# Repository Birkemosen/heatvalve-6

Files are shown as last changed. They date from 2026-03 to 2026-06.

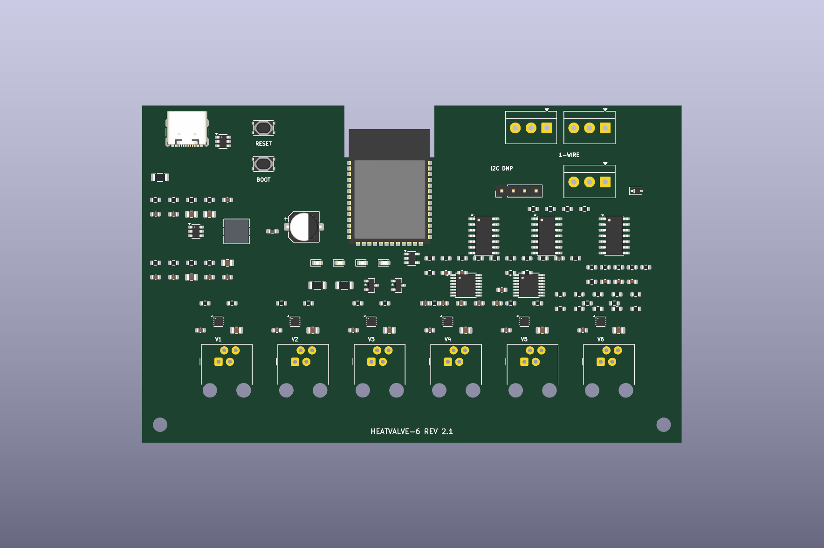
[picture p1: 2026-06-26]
hardware/heatvalve-6-rev2.1/board-preview.png

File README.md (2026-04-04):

# HeatValve-6

ESPHome firmware for the HeatValve-6 underfloor heating controller on ESP32-S3 with 6 DRV8215 I2C motor drivers.

This repository is now ESPHome-only. The legacy PlatformIO and ESP-IDF source tree has been removed.

## Repository Layout

```text
heatvalve-6/
├── heatvalve-6.yaml   # Main ESPHome firmware config
├── secrets.yaml       # Local secrets template (gitignored)
├── components/        # Custom ESPHome external components
│   ├── hv6_config_store/
│   ├── hv6_valve_controller/
│   └── hv6_zone_controller/
├── docs/
├── README.md
└── changelog.md
```

## What Is In The Firmware

- ESPHome on ESP-IDF
- 6-zone valve control with DRV8215 over I2C
- Custom C++ external components for config storage, valve control, and zone control
- Native ESPHome WiFi, API, OTA, web server, display, and climate entities
- DS18B20 1-Wire temperature sensors
- SSD1306 OLED support
- WS2812 status LED

## Hardware Mapping

| GPIO | Function |
|---|---|
| GPIO1 | Motor current sense ADC |
| GPIO2 | DRV8215 nSLEEP |
| GPIO7 | DRV8215 nFAULT |
| GPIO8 | I2C SDA |
| GPIO9 | I2C SCL |
| GPIO12 | 1-Wire bus |
| GPIO48 | WS2812 status LED |

### DRV8215 Addresses

| Zone | Address |
|---|---|
| 1 | 0x30 |
| 2 | 0x31 |
| 3 | 0x32 |
| 4 | 0x35 |
| 5 | 0x33 |
| 6 | 0x34 |

Only one motor should run at a time because current sensing is shared.

## Quick Start

1. Edit `secrets.yaml` with your WiFi, API, OTA, and optional MQTT values.
2. Replace the placeholder DS18B20 addresses in `heatvalve-6.yaml` after first discovery.
3. Build or deploy from the repo root.

Preferred workflow:

```bash
make build
make deploy
make logs
```

If you want USB flashing explicitly:

```bash
make deploy PORT=/dev/cu.usbmodemXXXX
```

If you want OTA to a specific host/IP:

```bash
make ota HOST=192.168.1.50
```

The `Makefile` automatically uses `.venv/bin/esphome` when present.

Direct ESPHome commands still work:

```bash
esphome run heatvalve-6.yaml
```

For config validation only:

```bash
esphome config heatvalve-6.yaml
```

## Notes

- The current firmware layout assumes the ESPHome config lives at the repository root.
- `secrets.yaml` is kept as a local template and remains gitignored.
- The repository has not been fully compile-tested yet after the migration.

## Documentation

- [docs/ARCHITECTURE.md](docs/ARCHITECTURE.md)
- [docs/ecodan_integration.md](docs/ecodan_integration.md)
- [docs/esp32-s3_ufh_pcb_solution.md](docs/esp32-s3_ufh_pcb_solution.md)
- [docs/schematics/rev3_wroom1/esp32_s3_wroom1_n16r8_controller.md](docs/schematics/rev3_wroom1/esp32_s3_wroom1_n16r8_controller.md)

## Inspiration & Credits

This project was inspired by and builds upon ideas from:

- [VdMot_Controller](https://github.com/Lenti84/VdMot_Controller) by Lenti84 — multiplexed motor control and current-based endstop detection for Homematic HmIP-VDMOT valve actuators
- [floor-heating-controller](https://github.com/nliaudat/floor-heating-controller) by nliaudat — BEMF analysis and trigger calculations for valve motor tachometry
- [Motor Controller Tachometer](https://yyao.ca/projects/motor_controller_tachometer/) by Yi Yao — back-EMF tachometer circuit design

## License

See [LICENSE](LICENSE) file.

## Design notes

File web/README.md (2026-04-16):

# HeatValve-6 ESP Dashboard

A lightweight, modular, framework-free dashboard optimized for ESPHome devices.

## Features
- Ultra-lightweight runtime
- Modular component system
- SSE real-time updates
- Offline mock mode
- SVG flow diagram with motor animation

## Structure
web/
  dashboard.js
  dashboard-src/
    core/
    utils/
    components/
    app/

## Usage
Include dashboard.js and mount to #app.

## Build
Use esbuild to bundle into a single file.

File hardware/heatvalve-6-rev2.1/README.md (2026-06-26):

# HeatValve-6 Rev 2.1 hardware

Editable KiCad 10 design for the USB-C-powered, six-channel DRV8837 HeatValve controller.

## Design state

- Schematic: complete first electrical-review revision; KiCad ERC reports 0 errors.
- PCB: compact four-layer 120 x 75 mm placement review with 128 electrical
  footprints, two M3 holes, an antenna notch, GND/+3V3 inner planes, and an
  intentionally unrouted ratsnest.
- Fabrication status: **not released**. Routing, mechanical confirmation, and final
  footprint/availability review are still required.
- PCB DRC: not current; KiCad CLI 10.0.3 aborts on both the original and updated
  board. See `drc.rpt` and rerun DRC in PCB Editor after routing.
- Prototype tuning: BEMF filter/gain/blanking, force threshold, engagement signature,
  and optional parallel shunt.

## Generate and validate

```bash
PYTHONPATH=/private/tmp/kicad_pydeps HOME=/private/tmp \
  python3 hardware/heatvalve-6-rev2.1/generate_kicad.py

kicad-cli sch erc \
  --output hardware/heatvalve-6-rev2.1/erc.rpt \
  hardware/heatvalve-6-rev2.1/heatvalve-6-rev2.1.kicad_sch

/Applications/KiCad/KiCad.app/Contents/Frameworks/Python.framework/Versions/3.9/bin/python3.9 \
  hardware/heatvalve-6-rev2.1/generate_pcb.py

kicad-cli pcb drc \
  --output hardware/heatvalve-6-rev2.1/drc.rpt \
  hardware/heatvalve-6-rev2.1/heatvalve-6-rev2.1.kicad_pcb
```

The committed `.kicad_sch` is usable without the Python generator dependency.

## Important design decisions

- Motors and logic operate from the MT2492-generated 3.3 V rail.
- Only one motor may run at a time.
- All DRV8837 ground returns meet at `SHUNT`; `RSH1` is the only normal return to system ground.
- `RSH1` is 1.0 ohm and INA180A1 provides x20 gain: 30 mA = 0.60 V,
  60 mA = 1.20 V, and 150 mA = 3.00 V. This preserves the pin-engagement peak.
- `R14`, `C13`, and `D5` provide additional ADC filtering and rail clamp protection.
- The hardware force-limit comparator reads the raw Kelvin shunt and remains effective if the ADC path saturates.
- Two 74HC4051 selectors connect only the active motor's A/B terminals to a
  shared differential BEMF front end. `ADC_BEMF` retains the raw waveform and
  `TACHO_EDGE` feeds PCNT after AC gain and hysteresis.
- Shunt ripple is not used as authoritative motion evidence. Firmware must qualify
  tacho edges against BEMF waveform, direction, switching blanking, and cadence.
- The latch powers up with `DRIVE_PERMIT` low and must be explicitly armed by firmware.
- Three OneWire connectors share GPIO42. The DNP I2C header uses GPIO1/GPIO2.
- Motor jacks use the center pair: pin 2 `MOT_A`, pin 3 `MOT_B`.

See `design-review.md` for calculations and release gates, and
`measurement-and-position.md` for engagement, modulation, endstop, and position logic.

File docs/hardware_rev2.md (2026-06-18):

# HeatValve-6 — Rev 2 board design (shared-shunt, dumb-driver)

Status: **design draft for a PCB respin.** Component values marked _(validate)_ are
reasoned starting points to confirm on a prototype channel, not final.

## 1. Goals

- **Safe, deterministic calibration** without the DRV8215's fragilities.
- **Fewest components / simplest layout** that is still **resilient** (per-zone failure
  granularity, no single-driver SPOF).
- Software-based hydraulic balancing (room-temp feedback, **no return probes** — see
  [adaptive_balancing.md](adaptive_balancing.md)), so per-loop return sensing is dropped.
- All parts orderable at LCSC/JLCPCB.

## 2. Architecture in one paragraph

Only one valve moves at a time, so **all sensing collapses onto a single shared low-side
shunt** (the VdMot insight). Six **dumb single H-bridges** (no I²C, no per-driver current
sense) are driven directly from GPIO and share one ground-return shunt. That one shunt
yields three things by splitting the signal: **DC current** (endstop/stall), **AC tacho**
(commutation ripple → edges → position), and a **hardware force-limit** (window comparator
with a firmware-set threshold → latch → global `nSLEEP` cutoff). This removes the six-way
IPROPI wire-OR, the I²C addressing, and the per-driver `RIPROPI` networks of the old board,
while *adding* a tacho and a force-limit it never had.

```mermaid
flowchart LR
  MCU[ESP32-S3-WROOM-1-N16R8]
  subgraph DRV[6x dumb single H-bridge DRV8837]
    D1[ch1] & D2[ch2] & D3[ch3] & D4[ch4] & D5[ch5] & D6[ch6]
  end
  SHUNT[shared low-side shunt Rs]
  FE[analog front-end]
  LATCH[force-limit latch]

  MCU -- PH/EN x6 --> DRV
  DRV -- all GND --> SHUNT --> FE
  FE -- DC current --> MCU
  FE -- AC tacho edges --> MCU
  MCU -- PWM-DAC threshold --> FE
  FE -- over-current --> LATCH
  MCU -- reset --> LATCH
  LATCH -- state --> MCU
  LATCH -- nSLEEP low = cut all --> DRV
  MCU -- BLE room temps --> MCU
  MCU -- 1-Wire manifold supply/return --> MCU
```

(A standalone, renderable version of this is in
[hardware_rev2_block.dot](hardware_rev2_block.dot) — `dot -Tsvg hardware_rev2_block.dot`.)

## 3. Power

| Rail | Source | Notes |
|---|---|---|
| `VM` (motor) | external supply (e.g. 12 V) | TVS (SMAJ-series) + bulk electrolytic + 100 nF per driver |
| `+3V3` | AP2112K-3.3 LDO (or small buck) | **≥ 500 mA** for WiFi TX peaks; bulk + local decoupling |
| `VBIAS` (≈½·3V3) | coarse divider from `+3V3` | AC-tacho bias only (centres the comparator); **not** a precision current ref |

## 4. Motor drivers — 6× dumb single H-bridge

- **DRV8837** (single H-bridge, `IN1`/`IN2` or `PH`/`EN`, `nSLEEP`, ~1.8 A, no sense, no
  I²C). Six identical blocks → copy-paste layout, **1-zone failure granularity**.
- Per driver: 2 control GPIO + `nSLEEP` + 100 nF decoupling + (optional) small output cap.
  **No `RIPROPI`, no current-set resistor, no I²C pull-ups.**
- **All six `nSLEEP` tie to one net = the force-limit "drive permit."** When the latch
  trips, `nSLEEP` → low → **all bridges Hi-Z instantly**, no per-driver AND gates needed.
- **Drive fixed duty** (`EN` high, no PWM/brake) during a move so the active motor's current
  flows continuously through the shunt → clean tacho + continuous current. Soft-approach near
  an endstop uses position (tacho), not duty chopping, to keep the ripple clean.

```
        VM
        │
   ┌────┴────┐  DRV8837 (one of six)
   │  H-brdg │  IN1 ◄─ GPIO_PHn
   │         │  IN2 ◄─ GPIO_ENn   (fixed-duty during move)
   │         │  nSLEEP ◄─ DRIVE_PERMIT (shared, from latch)
   └──┬───┬──┘
   OUT1   OUT2 ──► motor n
        │
       (chip GND)
        └──────────────► shared shunt node  (all six chip grounds join here)
```

## 5. Shared sense front-end (the heart of the board)

One shunt `Rs` in the **common return of all six driver grounds**. Because only one motor is
energized, `Rs` carries that motor's current (+ a small, calibratable quiescent offset from
the idle chips' awake current). **The current is unipolar**: a full H-bridge always sources
from `VM` and returns through GND no matter which way the motor spins, so the chip-GND shunt
only ever sees positive magnitude — *direction is known from the commanded `PH`*, not the
sign. (This is the key difference from VdMot, whose shunt sat in the motor common and so
swung bipolar and needed a `VREF/2` mid-rail.) That makes the front-end single-ended and the
force-limit a single comparator, not a window.

```
 driver GNDs ─┬─ Rs ─┬─ system GND      V_sense = I·Rs  (>= 0, unipolar)
              │      │
              │      ├─► [non-inv gain] ───────────────► ADC_CURRENT          (A) DC current
              │      │
              │      ├─► [HPF, bias=VBIAS] ─► [gain] ─► [comp + hyst] ─► PCNT  (B) tacho edges
              │      │
              │      └─► [comparator, thr = PWM-DAC] ──► LATCH                 (C) force-limit
```

`VBIAS` (≈ ½·3V3) is a **coarse divider**, used only to centre the AC-coupled tacho so the
comparator sees both edges — it is *not* a precision current reference (there isn't one).

### (A) DC current — endstop / stall / pin-engagement

- `Rs` ≈ **2.2 Ω _(validate)_** — at 50 mA → 110 mV; at a 100 mA stall ceiling → 220 mV;
  power < 25 mW. Drop is negligible vs `VM`.
- **Single-ended non-inverting amp** on `V_sense` (unipolar, sits at 0 V up), gain ≈
  **×8–10 _(validate)_** → ~1 V full-scale into the ADC. No precision reference needed.
- A constant **idle-chip offset** (all six share `nSLEEP`, so all are awake ~1–2 mA each)
  rides on `V_sense`; it's DC, so the firmware's per-pass `cal_baseline` subtracts it (same
  mechanism as today). If the offset is too large, lower `Rs` or gate `nSLEEP` per channel.
- Firmware uses it as today: endstop threshold `mean_dir × factor`, hard cap, undercurrent
  disconnect, pin-engagement step — direction comes from the commanded `PH`, not the sign.

### (B) AC tacho — commutation ripple → position

- AC-couple `V_sense` (high-pass corner ≈ **30 Hz _(validate)_**, below commutation rate but
  above the slow current ramp), gain ≈ **×50–100 _(validate)_** to lift the small ripple.
- Into a comparator with **~10–20 mV hysteresis _(validate)_** → clean digital edges → MCU
  **PCNT** peripheral (hardware edge count). Re-zeroed at each endstop to kill drift.
- This is VdMot's "back-EMF" revolution count, taken from the shared current node.

### (C) Force-limit — configurable, hardware-fast

- **Single comparator** (current is unipolar): `V_sense`-amp vs threshold, set by a
  **PWM-DAC**: one MCU `LEDC` PWM → RC low-pass → comparator reference. (ESP32-S3 has **no
  DAC**, so PWM-DAC; an MCP4725/digipot is the cleaner one-chip alternative.)
- **Per-motor ceiling**: reprogram the PWM-DAC to `mean_i × factor` from telemetry before
  starting motor *i* — one comparator gives a per-motor configurable stall limit.
- Comparator → **latch** (D-FF / SR) → drives `DRIVE_PERMIT` (= all `nSLEEP`). Trip cuts the
  active motor in **µs**, in hardware, independent of the 10 ms firmware tick.
- **Latch controls to MCU**: `RESET` (GPIO out — firmware decides re-arm policy: on back-off,
  after a dwell, or next command) and `STATE` (GPIO in — logged as a fault, feeds relearn).

## 6. Optional BEMF stop-sense (DNP, populate-if-needed)

For the spring-assisted **open** endstop, a magnitude-independent "stopped?" signal is the
ideal backstop. Tap the six motor `OUT1/OUT2` pairs through a `CD74HC4051` (8:1) → divider →
ADC, sampled in a brief coast window. **Lay out, leave unpopulated.** Validate current-ripple
+ current-stall first; populate only if the open stroke proves marginal (see §11).

## 7. MCU & pin budget (ESP32-S3-WROOM-1-N16R8)

Reserve/avoid: flash/PSRAM pins (octal PSRAM on **R8** uses GPIO35–37; flash GPIO26–32),
strapping (GPIO0, 3, 45, 46), USB (19/20 if used).

| Function | Count | Notes |
|---|---|---|
| Driver `PH` (direction) | 6 | GPIO out |
| Driver `EN` (fixed-duty/PWM) | 6 | GPIO/`LEDC` out |
| Tacho edges | 1 | → `PCNT` |
| Current sense | 1 | ADC1 (unipolar; baseline subtracted in firmware) |
| Force-limit threshold | 1 | `LEDC` PWM-DAC |
| Latch reset / state | 2 | GPIO out + in |
| 1-Wire (manifold supply+return) | 1 | DS18B20 ×2 on one bus |
| BLE / WiFi | 0 | on-module |
| **Optional** BEMF mux select + ADC | 3+1 | DNP |
| **Total (core)** | **~20** | comfortable on WROOM-1 |

> `nSLEEP` is **not** an MCU pin — it's the latch's `DRIVE_PERMIT` net. `EN` can be plain
> GPIO (fixed-duty) since force-limit is hardware; use `LEDC` only if you want PWM soft-start.

## 8. Sensors

- **Room temperature** = the balancing feedback: BLE (Shelly BLU H&T) per zone, as today.
- **Manifold supply + return** DS18B20 pair on one 1-Wire bus — diagnostics only.
- **Per-loop return probes: removed.** Not an input to the room-temp balancer.

## 9. BOM (verified against LCSC / JLCPCB, June 2026)

JLC status: **Basic** = preloaded, no per-part feeder fee; **Extended** = orderable, small
setup fee. Stock/status changes — reconfirm at order time on `jlcpcb.com/parts`. For jellybean
analog (LM324/LM339) pick whichever manufacturer variant JLC currently flags Basic/Preferred.

| Ref | Part | LCSC / JLC | JLC status | Qty | Notes |
|-----|---|---|---|-----|---|
| U1 | ESP32-S3-WROOM-1-N16R8 | **C2913202** | Extended (stocked) | 1 | 16 MB flash / 8 MB PSRAM; `-1U` = C3013946 |
| U2–U7 | DRV8837**DSGR** | **C39159** | Extended | 6 | dumb H-bridge, `IN1/IN2`, `nSLEEP`, `VM`+`VCC`; WSON-8. **Netlist targets this (non-C) pinout** — the `C` variant (C191000) drops `VCC` and re-maps pins, so don't swap without re-wiring |
| U8 | LM324 (quad op-amp) | **C351427** | Basic-class | 1 | current diff-amp + tacho gain + ref buffer (3 of 4) |
| U9 | LM339 (quad comparator) | **C504552** | Basic-class | 1 | tacho edge + force-limit window (3 of 4) |
| U10 | 74HC74D (dual D-FF) | **C27597** | Extended | 1 | force-limit latch (1 of 2) |
| U11 | AP2112K-3.3TRG1 | **C51118** | **Basic** | 1 | 3V3 LDO, 600 mA, SOT-25 |
| U12 | CD74HC4051PWR | **C352826** | Extended | 1 | **DNP** — optional BEMF mux (§6) |
| Rs | 2.2 Ω 0.25 W _(validate)_ | generic | Basic | 1 | shared shunt (1206 for power/heat) |
| D1 | SMAJ-series TVS (per `VM`) | generic | Basic | 1 | e.g. SMAJ15A for 12 V `VM` |
| C_bulk | 100–470 µF electrolytic | generic | Basic | 1–2 | `VM` bulk (motor inrush) |
| — | 100 nF ×~12, RC/divider/HPF passives | generic | Basic | — | decoupling, PWM-DAC RC, ref divider, AC-couple |

**Active-IC count: 10** (1 module + 6 drivers + 2 analog + 1 latch), of which only the module,
drivers, 74HC74 and (DNP) mux are Extended; everything else is JLC Basic. The two jellybean
analog ICs (LM324 + LM339) replace what would otherwise be six per-driver `RIPROPI`/sense
networks — they're the VdMot-precedented choice (VdMot used the LM224 = same LM324 family).

vs the old board: **− 6× `RIPROPI` networks, − I²C pull-ups/addressing, − per-driver config
passives; + 1 shunt, + LM324 + LM339, + 1 latch.** Net fewer parts, plus tacho + force-limit.

> Driver note: `DRV8837CDSGR` (C191000) is the cheapest well-stocked variant but is Extended.
> If you want to minimise Extended parts, `DRV8837DSGR` (**C39159**) is the other TI option;
> both are Extended (small H-bridges generally are). The LM324/LM339/AP2112K being Basic keeps
> the feeder-fee count low.

## 10. Net / connection list (capture this in EasyEDA/KiCad)

Power/ground nets omitted for brevity except where signal-relevant.

```
NET VM            : VMext, U2..U7.VM(1), C_bulk+, D1.cath              ; Rs is NOT here (low-side)
NET GND           : U1.GND, U11.GND(2), Rs.2, C_bulk-, U8.GND(11), U9.GND(12), U10.GND(7)
NET SHUNT         : Rs.1, U2..U7.GND(4), U8 current-amp in, U8 tacho AC-couple in, U9 force-limit in
NET VBIAS         : 3V3 divider mid, U8 tacho-amp bias, U9 tacho-comp ref     ; coarse, AC only
NET DRIVE_PERMIT  : U10.1Q(5), U2..U7.nSLEEP(7)                        ; latch trip -> all asleep
NET I_SENSE       : U8 current-amp out -> U1 ADC1 (GPIO4)
NET TACHO_EDGE    : U9 tacho-comp out -> U1 PCNT (GPIO15)              ; LM339 open-collector + pull-up
NET FLIM_THR      : U1 LEDC (GPIO16) -> RC -> U9 force-limit comp ref
NET FLIM_TRIP     : U9 force-limit comp out -> U10.1CLK(3)             ; open-collector + pull-up
NET LATCH_RESET   : U1 (GPIO17) -> U10.1nPRE(4)                        ; pulse low = re-arm (Q->1)
NET LATCH_STATE   : U10.1nQ(6) -> U1 (GPIO18)                          ; high = tripped (logged)
NET PH1..PH6      : U1 GPIO9..14 -> U2..U7.IN1(6)
NET EN1..EN6      : U1 GPIO47,48,38,39,40,41 -> U2..U7.IN2(5)
NET MOT1..MOT6    : U2..U7.OUT1(2)/OUT2(3) -> manifold actuator n
NET OW_MANIFOLD   : U1 (GPIO42) -> DS18B20 supply + return
; --- optional / DNP ---
NET BEMF_x        : U2..U7 OUT pairs -> U12 mux -> U1 ADC1 (GPIO6); mux sel -> U1 GPIO1,2,21
```
The machine-importable KiCad netlist of this is
[hardware_rev2.net](hardware_rev2.net) (`File > Import > Netlist` in EasyEDA / KiCad).
Op-amp/comparator support passives (gain resistors, hysteresis, pull-ups, PWM-DAC RC) are
included with _(validate)_ values — confirm on the prototype channel (§12).

## 11. Firmware mapping

- **PCNT** counts `TACHO_EDGE`; position = count from the last endstop re-zero. Flow band
  (pin-engagement → close) is the loaded, strong-ripple region — count there; coarse-time the
  open dead band.
- **ADC** reads `I_SENSE − VREF_HALF` (signed current) for endstop / stall / pin step.
- **LEDC PWM-DAC** sets `FLIM_THR = mean_i × factor` per motor before each move.
- **GPIO** drives `PH/EN` fixed-duty; reads `LATCH_STATE` (force-limit fired → fault/relearn),
  pulses `LATCH_RESET` per the chosen re-arm policy.
- Calibration logic (close→open→close, pin-engagement re-baseline, runtime cap) carries over;
  the tacho turns time-estimates into real position and makes already-at-stop detectable.

## 12. Bring-up / validation (prototype one channel first)

1. **Shunt + DC current**: drive a motor, confirm signed current matches a meter across the
   13–50 mA range; null the idle-chip quiescent offset via `VREF/2`.
2. **Tacho integrity** _(gate to populating all six)_: drive fixed-duty, verify the AC chain
   produces clean edges; count a full **flow-band** stroke, re-zero at close, check
   **repeatability within a few %**. Tune HPF corner / gain / hysteresis.
3. **Force-limit**: set `FLIM_THR` low, stall the motor, confirm `nSLEEP` cutoff in µs and the
   latch state/reset path; then set the real per-motor ceiling.
4. **Open endstop**: if the open stroke can't be caught reliably by current + tacho, **populate
   the BEMF path** and validate stop-by-BEMF.
5. Only then lay out and stuff all six identical blocks.

## 13. Resilience

- 6 independent bridges → **one driver dies = one zone**, rest keep running (same as today).
- Shared points: the shunt/front-end and the latch. Both are tiny, low-stress silicon; a
  front-end failure degrades to **open-loop time-driven** moves (limp mode), not loss of heat.
- NO valves fail **open** (warm) on power/driver loss — the safe direction for heating.
- Want lower part count over granularity? Swap 6 singles → **3 dual H-bridges** (DRV8833),
  2-zone granularity, same shunt/front-end.

## 14. Open items to finalize on the prototype

- `Rs` value + diff-amp gain for your exact `VM` and motor current band.
- Commutation-ripple frequency (sets the HPF corner and comparator hysteresis) — **measure**.
- Per-motor `factor` for the force-limit ceiling vs learned mean.
- Whether the BEMF path is needed (open-endstop margin).

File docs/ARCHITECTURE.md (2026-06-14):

# HeatValve-6 Architecture

## System Overview

HeatValve-6 is a 6-zone underfloor heating (UFH) valve controller built on ESP32-S3 with
ESPHome firmware. Custom C++ components run as FreeRTOS tasks alongside the ESPHome main
loop and separate hardware control (motor FSM, endstop detection) from heating logic
(zone state machine, control algorithms, hydraulic balance).

```
┌──────────────────────────────────────────────────────────────┐
│                     Config Composition                       │
│  configurations/heatvalve-6-ble.yaml → heatvalve-6.yaml      │
│  (substitutions + packages: board / hardware / network /     │
│   zones)                                                     │
└────────────────────────────┬─────────────────────────────────┘
                             ▼
┌──────────────────────────────────────────────────────────────┐
│                    Custom C++ Components                     │
│                                                              │
│  hv6_config_store ← hv6_valve_controller ← hv6_zone_controller
│                                                  ↑           │
│                                          hv6_asgard_bridge   │
│                                          hv6_forecast        │
│                                          hv6_dashboard       │
└────────────────────────────┬─────────────────────────────────┘
                             ▼
┌──────────────────────────────────────────────────────────────┐
│                       Hardware Layer                         │
│  • 6× DRV8215 I2C H-bridge motor drivers                     │
│  • Shared IPROPI current-sense ADC (GPIO7)                   │
│  • 1-Wire DS18B20 probes (8 slots)                           │
│  • BLE (BTHome / Shelly BLU H&T)                             │
│  • Status LED, display                                       │
└──────────────────────────────────────────────────────────────┘
```

## Repository Structure

```
heatvalve-6/
├── heatvalve-6.yaml          Shared base config (substitutions + packages)
├── configurations/
│   └── heatvalve-6-ble.yaml  Active build entrypoint (adds BLE package)
├── packages/
│   ├── board/                ESP32-S3 board definition
│   ├── hardware/             BLE, display, I2C, motors, LED, 1-Wire, sensors
│   ├── network/              WiFi, API, OTA, Asgard bridge, forecast
│   └── zones/                Climate entities, zone sensors, UI, dashboard wiring
├── components/               Custom ESPHome external components (C++)
│   ├── hv6_config_store/     NVS persistence (DeviceConfig struct)
│   ├── hv6_valve_controller/ Motor FSM, endstop detection, ripple counting
│   ├── hv6_zone_controller/  Zone state machine, algorithms, hydraulic balance
│   ├── hv6_asgard_bridge/    Weighted house temp → Asgard/Ecodan thermostat
│   ├── hv6_forecast/         Open-Meteo wind-aware per-zone preload
│   └── hv6_dashboard/        HTTP API (/api/hv6/v1), dashboard asset serving
├── web/
│   ├── dashboard-src/        Dashboard source (modular JS, esbuild)
│   └── dashboard.js          Bundled artifact (committed, embedded in firmware)
├── test/ripple_counter/      Host-side unit tests (clang++, no ESP-IDF)
├── docs/                     Architecture, API contract, integration docs
└── Makefile                  Build/deploy/test targets
```

## FreeRTOS Task Layout

| Task | Core | Priority | Period |
|---|---|---|---|
| `hv6_valve` (motor FSM) | 1 | 7 | 10 ms tick |
| `hv6_ripple` (DMA ADC) | 1 | 7 | continuous |
| `hv6_zone` (control cycle) | 0 | 6 | 10 s (configurable) |
| `hv6_asgard` (HTTP) | 1 | 1 | 30 s push (coordinator only) |
| `hv6_forecast` (HTTPS) | 1 | 1 | 1 h fetch / 5 min recompute |
| `hv6_nvs` (flash commit) | 1 | 1 | event-driven |
| ESPHome loopTask | 1 | 1 | — |

Cross-task state is exchanged via FreeRTOS queues and mutexes. Dashboard snapshots are
assembled in `hv6_dashboard::loop()` (main loop) under a dedicated `snapshot_mutex_`.

## Data Flow

### Local Control

```
Temp source (DS18B20 / BLE) → Zone state machine → Control algorithm → Hydraulic balance
                                   ↑                (tanh/linear/PID)        ↓
                              Setpoint + offsets                       Valve position
                                                                            ↓
                                                                   Motor FSM (one at a time)
                                                                            ↓
                                                                       DRV8215 I2C
```

### Setpoint-offset command path

On-device optimizers (currently `hv6_forecast`) write per-zone setpoint-offset / preheat
commands through `Hv6ZoneController::apply_helios_command()`. Offsets are clamped in
firmware by per-zone safety limits; if a producer goes stale, its offsets are cleared and
local control continues unchanged. `HeliosConfig.enabled` (NVS) acts as a quiesce gate so
a producer can stand down if an external optimizer is ever reintroduced.

Whole-house MPC is provided by Odin via the [Asgard / Ecodan bridge](ecodan_integration.md),
not an external HTTP optimizer — the previous `hv6_helios_client` was removed. Removing any
producer reverts transparently to local control: no vendor lock-in, no firmware dependency
on an external service.

## Hardware Layer

- **Motor Control**: 6× DRV8215 I2C H-bridges with shared IPROPI ADC current sensing
- **Constraint**: One motor at a time (all IPROPI outputs wire-ORed to GPIO7; the valve
  FSM enforces sequential execution)
- **Endstop Detection**: Four-path software detection (threshold, slope, hard cap, ripple
  limit) with per-direction parameters — see [endstop_detection.md](endstop_detection.md)
- **Sensors**: 1-Wire DS18B20 (8 slots, NVS-persisted ROM mapping), BLE BTHome
- **Communication**: WiFi, ESPHome native API (Home Assistant), HTTP/JSON (dashboard +
  Asgard bridge). No message broker — MQTT was removed in favor of plain HTTP over LAN.

## Dashboard API

Dashboard transport uses the dedicated `/api/hv6/v1` JSON namespace served by
`hv6_dashboard` on the device web server (port 80):

- The dashboard app is served at `/dashboard` (+ `/dashboard.js`)
- All dashboard reads/writes go through `/api/hv6/v1` — the dashboard must not call
  ESPHome entity REST routes (`/climate`, `/switch`, `/number`, …)
- Home Assistant integration continues through the ESPHome native API
- Contract: [hv6_api_v1.md](hv6_api_v1.md)

Frontend source lives under `web/dashboard-src/` and is bundled by esbuild into
`web/dashboard.js`, which is committed and embedded into the firmware at build time.

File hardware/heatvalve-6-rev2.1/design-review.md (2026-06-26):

# HeatValve-6 Rev 2.1 electrical design review

## Scope and status

This directory is the editable KiCad 10 implementation of Rev 2.1. The schematic
is suitable for detailed electrical review. The PCB is a placement baseline, not
a fabrication release: copper routing and mechanical fit still need to be completed.

## Current sensing and protection

`RSH1` is 1.0 ohm, with `RSH2` as a DNP parallel tuning footprint. All six driver
returns join the `SHUNT` side; only one valve may be driven at a time. `R13` makes
the single connection from the quiet shunt ground pickup to the main ground plane.

The INA180A1 gain is 20 V/V:

| Motor current | Shunt voltage | INA180 output |
|---:|---:|---:|
| 30 mA | 30 mV | 0.60 V |
| 60 mA | 60 mV | 1.20 V |
| 100 mA | 100 mV | 2.00 V |
| 150 mA | 150 mV | 3.00 V nominal |

This range preserves the temporary pin-engagement current peak instead of clipping it.
The LM339B force comparator independently reads the raw shunt node. The INA180 is
powered from 3.3 V, and `R14` plus the BAT54S clamp limit ADC injection during transients.

`FLIM_PWM` is filtered, attenuated by 9.1k/1k, and buffered. Its nominal 0–3.3 V
PWM-DAC range becomes approximately 0–174 mV at `FLIM_REF`, corresponding to a
raw-shunt threshold range of approximately 0–174 mA with the 1.0 ohm shunt.
The production setting must exceed measured startup and engagement peaks with margin,
while remaining below the destructive pop-off/grinding current.

## Differential BEMF and tacho

`U13` and `U14` are synchronized 74HC4051 selectors. GPIO-controlled
`BEMF_SEL[2:0]` selects the A and B terminals of the one active motor; codes 6 and 7
select grounded spare channels. Each exposed motor terminal enters through a 10k
current-limiting resistor before the analog selector.

The matched terminal/input and feedback network (`10k + 90.9k`, with 47k feedback)
produces approximately:

```text
BEMF_RAW = VBIAS + 0.466 * (MOT_B - MOT_A)
```

This keeps a nominal full-rail differential inside the 3.3 V analog domain.
`ADC_BEMF` is the protected raw ADC channel for waveform capture, coast-window
measurement, and motion validation. A separate AC-coupled x11 stage and LM339B
comparator produce `TACHO_EDGE` for ESP32 PCNT.

The comparator output is not sufficient by itself. Switching transitions must be
blanked, edge intervals must match a physically plausible commutation cadence, and
firmware must confirm motion using the raw BEMF waveform. If continuous-drive sensing
is not clean enough, firmware shall briefly command both DRV8837 inputs low, allow the
recirculation transient to decay, sample differential BEMF, and resume drive.

## Fail-safe behavior

The 74HC74 power-on RC holds asynchronous clear active, so `DRIVE_PERMIT` starts
low. Firmware explicitly arms the latch with a low pulse on `LATCH_ARM_N`. A rising
overcurrent comparator edge clocks D=0, dropping `DRIVE_PERMIT`; `LATCH_STATE`
is the complementary fault indication. `R29` also pulls permit low if the latch
output is not actively valid.

Firmware must never rely on the hardware latch as the normal stop mechanism, and
must still enforce the one-motor-at-a-time constraint.

## External interfaces

- USB-C USB 2.0 UFP: 5.1k CC resistors, USBLC6-2SC6 ESD, 22 ohm data resistors.
- Six 4P4C jacks: pin 1 NC, pin 2 MOT_A, pin 3 MOT_B, pin 4 NC.
- BEMF selector GPIOs: `BEMF_SEL0`, `BEMF_SEL1`, `BEMF_SEL2`; code 0–5 selects valve 1–6.
- Analog diagnostics: `ADC_CURRENT`, `ADC_BEMF`; pulse counter: `TACHO_EDGE`.
- Three shared OneWire connectors: pin 1 +3V3, pin 2 DQ, pin 3 GND; 33 ohm source
  resistor, 4.7k pull-up, and ESD diode.
- DNP I2C header: pin 1 GND, pin 2 +3V3, pin 3 SDA/GPIO1, pin 4 SCL/GPIO2, with
  DNP 2.2k pull-ups.

## PCB stack and placement intent

- Board: 120 x 75 mm, four layers, two 3.2 mm M3 mounting holes.
- Top: components and signal routing.
- Inner 1: continuous GND reference plane.
- Inner 2: +3V3_SYS distribution plane, split/necked as required around analog routing.
- Bottom: return/power routing and low-priority signals where needed.
- The ESP32 antenna bridges a 20 x 11.5 mm U-notch cut into the top board edge;
  the wider module keepout remains free of copper and parts.
- Six drivers form repeated lanes directly above their 4P4C connectors.
- Shunt/INA/BEMF-selector/tacho/latch circuitry occupies the center analog region.

## Release gates

1. Confirm enclosure, connector pitch, USB opening, board outline, and mounting holes.
2. Confirm exact purchasable MPNs for the buck inductor, shunt, terminal blocks,
   USB connector, LEDs, and all protection parts.
3. Route the shunt as a true star return and route two Kelvin traces directly from
   `RSH1` pads; do not sample the high-current copper elsewhere.
4. Route USB D+/D- as a short, length-matched 90 ohm differential pair over GND.
5. Route each WSON motor output with a narrow neck-down escape, then widen to at
   least 0.5 mm; add thermal/return vias according to the DRV8837 layout guidance.
6. Keep PWM, motor outputs, and buck switch node away from Kelvin traces,
   `BEMF_MUX_A/B`, `BEMF_RAW`, `BEMF_AC`, `FLIM_REF`, and both ADC traces.
7. Fill planes, run final KiCad DRC with zero errors/unconnected items, inspect
   Gerbers and drill files, then perform an independent schematic/PCB review.
8. Prototype with one populated motor lane first; tune coast blanking, BEMF gain,
   tacho cadence filtering, and force threshold before populating all six lanes.

## Prototype validation

1. Current-limited USB supply: verify no unintended motor enable during ramp/reset.
2. Check 3.3 V regulation, ripple, thermal rise, and worst-case USB current.
3. Verify native USB programming and ESD-protected data integrity.
4. Calibrate ADC current at 10, 30, 60, 100, and 150 mA. Capture startup and
   pin-engagement peaks without clipping.
5. Sweep `FLIM_PWM`, measure the raw-shunt trip threshold, and verify the latch trips
   with firmware stalled and stays tripped until explicitly re-armed.
6. Capture simultaneous `ADC_CURRENT`, `ADC_BEMF`, driver inputs, and `TACHO_EDGE`
   during free travel, pin engagement, loaded modulation, closed stop, open stop,
   mid-stroke obstruction, and disconnected-motor tests.
7. Tune C53/C54, x11 gain, hysteresis, switching blanking, and optional coast-window
   delay. Confirm a stalled motor cannot generate accepted position counts.
8. Learn open, engagement, and closed commutation landmarks over at least 20 cycles
   per actuator. Quantify missed/double edges and directional backlash.
9. Verify normal engagement cannot trip the hardware latch, while destructive current
   trips it with firmware stalled.
10. Validate OneWire with three branches and worst-case cable lengths before final routing.

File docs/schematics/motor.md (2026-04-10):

# Motor Driver Schematic

## Overview

6x DRV8215 single H-bridge motor drivers, one per valve motor. Each motor has a dedicated
full H-bridge with bidirectional drive (OUT1, OUT2). All control via I2C bus (I2C_BC=1 mode).
No multiplexing, no optocouplers, no shared motor-negative path.

Assembly: Aisler (DRV8215RTER sourced from Mouser/Digikey).

## Block Diagram

```
                              HeatValve-6 Rev.2 : Motor Drivers
  ┌─────────────────────────────────────────────────────────────────────────────┐
  │                                                                             │
  │  ◄── 3V3 (from Power, MT2492) ═══════════════════════════════════╗     │
  │  ◄── GND ════════════════════════════════════════════════════════╗║     │
  │                                                                  ║║     │
  │  ◄── I2C_SCL (GPIO8) ──────────────────────────┐                ║║     │
  │  ◄── I2C_SDA (GPIO9) ─────────────────────────┐│                ║║     │
  │                                                ││                ║║  ║     │
  │       ┌──────────────┐  ┌──────────────┐  ┌──────────────┐     ║║  ║     │
  │       │  DRV8215 #1  │  │  DRV8215 #2  │  │  DRV8215 #3  │     ║║  ║     │
  │       │  (U4)        │  │  (U5)        │  │  (U6)        │     ║║  ║     │
  │       │  Addr: 0x30  │  │  Addr: 0x31  │  │  Addr: 0x32  │     ║║  ║     │
  │       │  A1=L A0=L   │  │  A1=L A0=Z   │  │  A1=L A0=H   │     ║║  ║     │
  │       │              │  │              │  │              │     ║║  ║     │
  │       │  VM←3V3      │  │  VM←3V3      │  │  VM←3V3      │     ║║     │
  │       │  VCC←3V3     │  │  VCC←3V3     │  │  VCC←3V3     │     ║║     │
  │       │  SDA,SCL←I2C │  │  SDA,SCL←I2C │  │  SDA,SCL←I2C │     ║║     │
  │       │  OUT1──→J2   │  │  OUT1──→J3   │  │  OUT1──→J4   │     ║║     │
  │       │  OUT2──→J2   │  │  OUT2──→J3   │  │  OUT2──→J4   │     ║║     │
  │       └──────────────┘  └──────────────┘  └──────────────┘     ║║     │
  │                                                                  ║║     │
  │       ┌──────────────┐  ┌──────────────┐  ┌──────────────┐     ║║     │
  │       │  DRV8215 #4  │  │  DRV8215 #5  │  │  DRV8215 #6  │     ║║     │
  │       │  (U7)        │  │  (U8)        │  │  (U9)        │     ║║     │
  │       │  Addr: 0x33  │  │  Addr: 0x34  │  │  Addr: 0x35  │     ║║     │
  │       │  A1=Z A0=L   │  │  A1=Z A0=Z   │  │  A1=Z A0=H   │     ║║     │
  │       │              │  │              │  │              │     ║║     │
  │       │  OUT1──→J5   │  │  OUT1──→J6   │  │  OUT1──→J7   │     ║║     │
  │       │  OUT2──→J5   │  │  OUT2──→J6   │  │  OUT2──→J7   │     ║║     │
  │       └──────────────┘  └──────────────┘  └──────────────┘     ║║     │
  │                                                                  ║║     │
   │  ◄── nSLEEP_ALL (GPIO6) ──→ shared nSLEEP on all 6 chips       ║║     │
  │  ◄── nFAULT_ALL (GPIO4) ←── wired-OR nFAULT from all 6 chips   ║║     │
   │  ◄── IPROPI_ADC (GPIO7) ←── shared R7 from all 6 IPROPI        ║║     │
   │  ◄── RC_OUT_ALL (DRV pin 3) ← shared R9 from all 6 pin 3 (DRV8214 only)║║ │
  │                                                                  ║║  ║     │
  └─────────────────────────────────────────────────────────────────────────────┘

  Signal flow: ESP32 I2C → DRV8215 registers → OUT1/OUT2 → Motor (via RJ11)
                ESP32 GPIO6 → shared nSLEEP (wake/sleep all chips)
               ESP32 GPIO4 ← wired-OR nFAULT (any chip fault)
                ESP32 GPIO7 (ADC) ← R7 (proportional motor current)
                RC_OUT_ALL is DRV pin 3 and is not used with DRV8215
```

## Architecture

Each DRV8215 is controlled entirely via I2C (I2C_BC=1). No GPIO needed for direction
or enable per motor. Only 2 GPIO for I2C bus (shared), plus 1 shared nSLEEP, 1 shared
nFAULT, and 1 ADC for IPROPI.

```
I2C bus (GPIO8 SCL, GPIO9 SDA) ──┬── DRV8215 #1 (0x30) ─── OUT1/OUT2 → Motor 1
                                  ├── DRV8215 #2 (0x31) ─── OUT1/OUT2 → Motor 2
                                  ├── DRV8215 #3 (0x32) ─── OUT1/OUT2 → Motor 3
                                  ├── DRV8215 #4 (0x33) ─── OUT1/OUT2 → Motor 4
                                  ├── DRV8215 #5 (0x34) ─── OUT1/OUT2 → Motor 5
                                  └── DRV8215 #6 (0x35) ─── OUT1/OUT2 → Motor 6

GPIO6 ────→ shared nSLEEP (all 6 chips)
GPIO4 ←──── wired-OR nFAULT (R8 pull-up to 3V3)
GPIO7 ←──── R7 (5.1kΩ to GND, all 6 IPROPI wire-OR)
RC_OUT_ALL ← R9 (all 6 DRV pin 3 lines wire-OR, relevant to DRV8214; NC on DRV8215)
```

Only one motor runs at a time (firmware-enforced invariant). Inactive motors are in
coast mode (I2C_EN_IN1=0), so their IPROPI output is zero. The active motor's current
appears on the shared R7 resistor as a voltage readable by ESP32 ADC.

## DRV8215 Motor Drivers (U4 through U9)

Texas Instruments DRV8215 - 4A peak single H-bridge motor driver with I2C control,
integrated current sensing (IPROPI), hardware stall detection, and speed/voltage regulation.

### DRV8215 Pin Connections (WQFN-16, 3×3mm)

| Pin | Name | Net (all 6 chips) | Connection |
|-----|---|---|---|
| 1 | IPROPI | IPROPI_BUS | → wire-OR to shared R7 (5.1kΩ) → GND |
| 2 | VCC | 3V3 | Logic supply (MT2492 output) |
| 3 | RSVD/RC_OUT | RC_OUT_ALL | → wire-OR to shared R9 (10kΩ pull-down) → GPIO3. NC on DRV8215; becomes RC_OUT on DRV8214 |
| 4 | nFAULT | nFAULT_ALL | Open-drain, wired-OR → R8 (10kΩ) → 3V3 |
| 5 | VM | 3V3 | Motor supply (MT2492 output) |
| 6 | OUT1 | Mx_OUT1 | → RJ11 connector pin 1 (motor positive) |
| 7 | GND | GND | Ground plane |
| 8 | OUT2 | Mx_OUT2 | → RJ11 connector pin 3 (motor negative) |
| 9 | A1 | (per chip) | I2C address select, tri-level |
| 10 | A0 | (per chip) | I2C address select, tri-level |
| 11 | nSLEEP | nSLEEP_ALL | ← GPIO2 (shared, active HIGH) |
| 12 | PH/IN2 | NC | Not used (I2C_BC=1, control via I2C) |
| 13 | EN/IN1 | NC | Not used (I2C_BC=1, control via I2C) |
| 14 | SDA | I2C_SDA | ← GPIO9 (shared I2C bus) |
| 15 | SCL | I2C_SCL | ← GPIO8 (shared I2C bus) |
| 16 | VREF | 3V3 (VCC) | Tied to VCC; with INT_VREF=1b internal 500mV is used. Per TI Figure 9-1 |
| PAD | GND | GND | Thermal pad → ground plane via vias |

Component: DRV8215RTER, WQFN-16 (3×3mm), Digikey 296-DRV8215RTER-ND (~€1.35/unit)

Notes:
- EN/IN1 and PH/IN2 pins are unused when I2C_BC=1. Internal pulldowns hold them LOW.
- VREF pin tied to VCC (3V3) per TI reference design (Figure 9-1). With INT_VREF=1b, internal
  500mV is used for stall detection; VREF pin voltage ignored. VCC bypass cap filters VREF.
  Leaving VREF floating (NC) is bad practice for analog inputs — can pick up noise.
- Pin 3 (RSVD) is NC on DRV8215. Trace to RC_OUT_ALL net is pre-routed for DRV8214 upgrade.
- nSLEEP has internal pulldown (~200kΩ); chip sleeps by default at power-up.

### I2C Address Configuration

Tri-level pins: GND (L), floating/Hi-Z (Z), VCC (H). 9 unique addresses possible.
We use 6 addresses for 6 motors.

| Motor | Chip | A1 Pin | A0 Pin | 8-bit Write | 7-bit (ESPHome) |
|---|---|---|---|---|---|
| 1 | U4 | GND | GND | 0x60 | 0x30 |
| 2 | U5 | GND | Hi-Z | 0x62 | 0x31 |
| 3 | U6 | GND | VCC | 0x64 | 0x32 |
| 4 | U7 | Hi-Z | GND | 0x66 | 0x33 |
| 5 | U8 | Hi-Z | Hi-Z | 0x68 | 0x34 |
| 6 | U9 | Hi-Z | VCC | 0x6A | 0x35 |

- A0/A1 Hi-Z = leave pin unconnected (internal bias: 10µA pullup to VCC + 90kΩ pulldown to GND)
- A0/A1 GND = connect directly to GND
- A0/A1 VCC = connect directly to VCC (3V3)
- Address pins are latched at power-up

### Per-Chip Address Pin Wiring

| Chip | A1 Connection | A0 Connection |
|---|---|---|
| U4 | Direct to GND | Direct to GND |
| U5 | Direct to GND | Unconnected (Hi-Z) |
| U6 | Direct to GND | Direct to VCC (3V3) |
| U7 | Unconnected (Hi-Z) | Direct to GND |
| U8 | Unconnected (Hi-Z) | Unconnected (Hi-Z) |
| U9 | Unconnected (Hi-Z) | Direct to VCC (3V3) |

### DRV8215 H-Bridge Truth Table (Phase-Enable mode, I2C_BC=1)

| nSLEEP | I2C_EN_IN1 | I2C_PH_IN2 | OUT1 | OUT2 | Function |
|---|---|---|---|---|---|
| 0 | X | X | Hi-Z | Hi-Z | Sleep (<100nA) |
| 1 | 0 | X | Hi-Z | Hi-Z | Coast (motor disconnected) |
| 1 | 1 | 0 | L | H | Reverse (close valve) |
| 1 | 1 | 1 | H | L | Forward (open valve) |

Brake: set I2C_EN_IN1=1, I2C_PH_IN2=0 with PMODE=0 (PWM mode variant).

### DRV8215 Decoupling (per driver, ×6)

3 caps per driver, sequentially numbered C8–C25:

| Driver | VM Bulk (10µF, C0603) | VM HF (100nF, C0402) | VCC HF (100nF, C0402) |
|---|---|---|---|
| U4 | C8 | C9 | C10 |
| U5 | C11 | C12 | C13 |
| U6 | C14 | C15 | C16 |
| U7 | C17 | C18 | C19 |
| U8 | C20 | C21 | C22 |
| U9 | C23 | C24 | C25 |

Notes:
- Place decoupling caps as close to DRV8215 VM and VCC pins as possible
- VM (pin 5) = 3V3 (from MT2492 buck converter)
- VCC (pin 2) = 3V3 (from MT2492 buck converter)
- GND pad (thermal) must connect to ground plane via multiple vias (≥4)

### IPROPI Current Sensing (Shared)

The DRV8215 includes an internal current mirror on the low-side FETs. The IPROPI pin
outputs a current proportional to the motor load current. An external resistor converts
this current to a voltage for ADC measurement.

All 6 IPROPI pins (pin 1) wire-OR to a single shared R7 resistor to GND.
Only the active motor outputs current on IPROPI; inactive motors in coast mode
(I2C_EN_IN1=0) have their low-side FETs off, so IPROPI output current is zero.
No isolation diodes needed: IPROPI is a current source output (high impedance when
inactive), not a voltage source.

```
DRV8215 #1 IPROPI (pin 1) ──┐
DRV8215 #2 IPROPI (pin 1) ──┤
DRV8215 #3 IPROPI (pin 1) ──┤
DRV8215 #4 IPROPI (pin 1) ──┼── IPROPI_BUS ── R7 (5.1kΩ) ── GND
DRV8215 #5 IPROPI (pin 1) ──┤                    │
DRV8215 #6 IPROPI (pin 1) ──┘                    └── GPIO1 (ADC)
```

| Ref | Value | Footprint | Net From | Net To | Purpose |
|-----|---|---|---|---|---|
| R7 | 5.1kΩ | R0603 | IPROPI_BUS | GND | Shared current sense resistor |

#### Optional RC Filter (Jumper-selectable)

To keep first hardware revision flexible, IPROPI includes an optional RC low-pass branch
that can be enabled later without PCB respin.

Default build: **bypass path ON**, **RC path OFF**.

```
IPROPI_BUS ---- SJ_IP_BYP (default: CLOSED) -------------------- GPIO1 (ADC)
      |
      +-- R_IPF (1.0k) --o-- SJ_IP_RC (default: OPEN) ---------- GPIO1 (ADC)
                         |
                        C_IPF (100nF)
                         |
                        GND
```

| Ref | Value | Footprint | Default | Purpose |
|-----|---|---|---|---|
| SJ_IP_BYP | Solder jumper | 3-pad | Closed | Direct IPROPI path to ADC |
| R_IPF | 1.0kΩ | R0603 | Populated | RC series resistor (when filter enabled) |
| C_IPF | 100nF | C0603 | Populated | RC shunt capacitor to GND |
| SJ_IP_RC | Solder jumper | 3-pad | Open | Connect RC-filtered node to ADC |

Filter math (when RC path is enabled):

- `f_c = 1 / (2πRC) = 1 / (2π * 1k * 100nF) ≈ 1.59 kHz`
- HmIP-VDMOT ripple band (~15-35 Hz) is effectively unaffected:
  - Gain at 35 Hz: `~0.9998` (negligible attenuation)
- High-frequency switching/EMI is strongly attenuated:
  - Gain at 600 kHz (buck switching region): `~0.00265` (~ -51.5 dB)

Recommended usage:
- **Calibration/ripple characterization:** use bypass path (default)
- **If ADC noise appears in field tests:** switch to RC path

#### Current Mirror Gain Settings (CS_GAIN_SEL)

| CS_GAIN_SEL | AIPROPI (µA/A) | Current Range | OCP Limit | Low-side RDS(on) |
|---|---|---|---|---|
| 000b | 244 | 350mA - 2A | 4A | 145 mΩ |
| 010b | 1156 | 60mA - 350mA | 0.8A | 530 mΩ |
| 110b | 5320 | 10mA - 60mA | 0.16A | 2450 mΩ |

**Selected: CS_GAIN_SEL = 110b** (5320 µA/A) — optimal for HmIP-VDMOT motors
running at 20-60mA typical current. Provides best resolution at low currents.

#### RIPROPI Calculation

V_IPROPI = I_motor × AIPROPI × R7

R7 is set to 5.1kΩ as a headroom compromise for HmIP-VDMOT current profiles: still high
resolution in the 20-40mA operating range, with later saturation (~75mA instead of ~62mA).

| Motor Current | IPROPI Current | V_IPROPI (5.1kΩ) | ADC Reading (12-bit, 3.1V ref) |
|---|---|---|---|
| 10mA | 53.2µA | 0.27V | ~114 |
| 20mA | 106.4µA | 0.54V | ~227 |
| 40mA | 212.8µA | 1.09V | ~454 |
| 60mA | 319.2µA | 1.63V | ~681 |
| 80mA (stall) | 425.6µA | 2.17V | ~907 (clips near limit) |

Maximum IPROPI voltage: min(VM - 1.25V, 3.3V) = min(3.3 - 1.25, 3.3) = 2.05V.
At currents above ~75mA, IPROPI compresses/saturates near ~2.05V. This is acceptable for
HeatValve-6 because only one motor runs at a time and high-current protection is handled by
DRV8215 hardware (EN_STALL + OCP). IPROPI is used primarily for low-current profile tracking
and endstop trend detection in the normal operating range.

### nFAULT (Shared, Wired-OR)

All 6 nFAULT pins (pin 4, open-drain) connect to a single pull-up resistor.
Any chip asserting a fault pulls the line LOW.

| Ref | Value | Footprint | Net From | Net To | Purpose |
|-----|---|---|---|---|---|
| R8 | 10kΩ | R0603 | nFAULT_ALL | 3V3 | Shared nFAULT pull-up |

### nSLEEP (Shared)

All 6 nSLEEP pins (pin 11) connect to GPIO2. Assert HIGH to wake all chips,
LOW to put all in sleep mode (<100nA per chip).

### VREF Configuration

VREF pin (pin 16) tied to VCC (3V3) on all chips, per TI reference design (Figure 9-1).
With INT_VREF=1b (register default), the internal 500mV reference is used for stall
detection and the VREF pin voltage is ignored. No additional bypass cap needed — VREF
shares VCC's existing 100nF decoupling. Primary stall/endstop detection is software-based
via IPROPI ADC monitoring.

### RC_OUT (Shared, DRV8214 Future)

All 6 RSVD/RC_OUT pins (pin 3) connect to a shared pull-down resistor.
On DRV8215, pin 3 is reserved (Hi-Z) — the pull-down keeps RC_OUT_ALL stable at GND.
On DRV8214, RC_OUT pulses on each detected motor commutation ripple.

| Ref | Value | Footprint | Net From | Net To | Purpose |
|-----|---|---|---|---|---|
| R9 | 10kΩ | R0603 | RC_OUT_ALL | GND | Shared RC_OUT pull-down (DRV8214 ready) |

RC_OUT_ALL → GPIO3 (interrupt input for hardware ripple counting when using DRV8214).

## Stall / Endstop Detection

### Strategy: Software-Primary with Hardware Safety

HmIP-VDMOT motors have a gradual current profile (measured by
[VdMot Controller](https://github.com/Lenti84/VdMot_Controller/blob/master/system/actuators.md)):
- Free running: ~20-25mA
- Spindle contacts valve pin (~position 2600): +4-5mA step
- Linear compression phase: gradual increase
- Rubber compression (~position 6300+): steeper ramp to endstop

A fixed hardware threshold cannot distinguish these phases. Software monitoring of
IPROPI ADC gives detailed visibility into the current profile in the normal current range.

### Hardware OCP (Safety Ceiling)

DRV8215 built-in overcurrent protection (OCP) acts as a hard safety limit.
With CS_GAIN_SEL=110b: OCP triggers at 160mA — well above any normal operating
current. This prevents damage if motor is physically blocked or shorted.

EN_STALL enabled with INT_VREF=1b (500mV, ~94mA threshold) provides a secondary
hardware safety net. SMODE=1b reports stall via nFAULT but continues driving,
giving firmware time to react.

| Register | Bit | Value | Description |
|---|-----|---|---|
| CONFIG0 (0x09) | EN_STALL | 1b | Enable hardware stall detection (safety net) |
| CONFIG3 (0x0C) | SMODE | 1b | Report stall but continue driving |
| CONFIG3 (0x0C) | IMODE | 00b | No current regulation |
| CONFIG3 (0x0C) | INT_VREF | 1b | Internal 500mV reference (~94mA threshold) |
| CONFIG0-1 | TINRUSH | tunable | Startup blanking time |

### Software Stall Detection (Primary)

1. Motor starts → ESP32 samples IPROPI via ADC (GPIO1) at 100-1000 Hz
2. Firmware monitors current level and rate-of-change
3. Detect valve contact: current step of ~4-5mA above baseline
4. Detect endstop: sustained current above threshold (tunable in firmware)
5. Firmware stops motor by writing I2C_EN_IN1=0
6. nFAULT interrupt (GPIO4) as backup if hardware threshold is exceeded

## Software Ripple Counting (Optional)

Motor commutation creates periodic current ripples visible on IPROPI. By sampling at
high rate and filtering, motor position can be tracked without external sensors.

### Implementation

1. ESP32-S3 ADC in continuous DMA mode on GPIO1 (IPROPI_BUS)
2. Sample rate: 1-10 kHz (ESP32-S3 supports up to 83kHz per channel)
3. Software bandpass filter tuned to motor commutation frequency (~25-65 Hz)
4. Peak/zero-crossing counter for position tracking
5. Custom C++ ESPHome component required

### Ripple Signal Characteristics

HmIP-VDMOT motors have 2600-6300+ commutator steps per full stroke (~3 minutes).
At typical speed: ~15-35 steps/second = ~15-35 Hz ripple frequency.

With CS_GAIN_SEL=110b and R7=5.1kΩ, ripple amplitude at 20-40mA base current
is approximately 40-165mV peak-to-peak on the IPROPI_BUS — well within ESP32 ADC
resolution (0.76mV/LSB at 12-bit).

## Motor Connectors (5301-4P4C, 4-pin)

6× 5301-4P4C RJ11 connectors along the bottom edge of the PCB.
Motor cable has only two wires, to pin 1 and pin 3.

### RJ11 Pin Assignment (per connector)

| Pin | Net | Description |
|-----|-----|---|
| 1 | Mx_OUT1 | Motor positive (from DRV8215 OUT1, pin 6) |
| 2 | NC | Not connected |
| 3 | Mx_OUT2 | Motor negative (from DRV8215 OUT2, pin 8) |
| 4 | NC | Not connected |

Homematic HmIP-VDMOT compatible: motor uses only **pin 1 and pin 3**; pins 2 and 4 are NC.

### Motor Connector Assignments

| Ref | Motor | DRV8215 | OUT1 Net | OUT2 Net | I2C Addr (7-bit) |
|-----|---|---|---|---|---|
| J2 | Motor 1 | U4 | M1_OUT1 | M1_OUT2 | 0x30 |
| J3 | Motor 2 | U5 | M2_OUT1 | M2_OUT2 | 0x31 |
| J4 | Motor 3 | U6 | M3_OUT1 | M3_OUT2 | 0x32 |
| J5 | Motor 4 | U7 | M4_OUT1 | M4_OUT2 | 0x33 |
| J6 | Motor 5 | U8 | M5_OUT1 | M5_OUT2 | 0x34 |
| J7 | Motor 6 | U9 | M6_OUT1 | M6_OUT2 | 0x35 |

Each motor has its own dedicated H-bridge. Full bidirectional drive via OUT1/OUT2.

## I2C Motor Control Sequence

1. **Wake**: Assert nSLEEP_ALL HIGH (GPIO2). Wait tWAKE (~410µs).
2. **Configure** (once after boot, per chip):
   - Write CONFIG4 (0x0D): I2C_BC=1, PMODE=1 (Phase-Enable mode), I2C_EN_IN1=0
   - Write CONFIG3 (0x0C): IMODE=00b (no current regulation), SMODE=1b (stall report only), INT_VREF=1b
   - Write CONFIG0 (0x09): EN_STALL=1
   - Write RC_CTRL0 (0x11): CS_GAIN_SEL=110b (5320µA/A, 10-60mA range)
3. **Single-motor guard**: Ensure all motors are in coast before starting one motor.
4. **Start motor**: Write CONFIG4 (0x0D): I2C_EN_IN1=1, I2C_PH_IN2=direction
5. **Monitor**: Poll FAULT_STATUS (0x00) for STALL bit; read IPROPI via ADC
6. **Stop motor**: Write CONFIG4 (0x0D): I2C_EN_IN1=0 (coast mode)
7. **Sleep**: De-assert nSLEEP_ALL LOW (GPIO2) when all motors idle

## PCB Layout Notes

- Place each DRV8215 close to its RJ11 connector for short OUT1/OUT2 traces
- Spread DRV8215s along the bottom edge of PCB
- Keep motor power traces (OUT1, OUT2) ≥0.5mm wide
- VM and VCC decoupling caps directly adjacent to pins 5 and 2 respectively
- GND thermal pad: ≥4 thermal vias to internal ground plane
- I2C traces (SDA, SCL): route together, away from motor outputs (≥0.3mm clearance)
- IPROPI bus: short traces, star topology from R7 to each chip
- nFAULT and nSLEEP: can be thin traces (0.2mm, digital)
- 3V3 power feed: thick trace (≥0.75mm) or power plane for VM+VCC combined

## BOM Summary (Motor Section)

| Ref | Component | Value | Footprint | Source | Notes |
|-----|---|---|---|---|---|
| U4 | DRV8215RTER | - | WQFN-16 (3×3mm) | Digikey 296-DRV8215RTER-ND | Motor 1, addr 0x30 |
| U5 | DRV8215RTER | - | WQFN-16 (3×3mm) | Digikey | Motor 2, addr 0x31 |
| U6 | DRV8215RTER | - | WQFN-16 (3×3mm) | Digikey | Motor 3, addr 0x32 |
| U7 | DRV8215RTER | - | WQFN-16 (3×3mm) | Digikey | Motor 4, addr 0x33 |
| U8 | DRV8215RTER | - | WQFN-16 (3×3mm) | Digikey | Motor 5, addr 0x34 |
| U9 | DRV8215RTER | - | WQFN-16 (3×3mm) | Digikey | Motor 6, addr 0x35 |
| R7 | Resistor | 5.1kΩ | R0603 | Aisler Lovely Lib | Shared IPROPI sense |
| R8 | Resistor | 10kΩ | R0603 | Aisler Lovely Lib | Shared nFAULT pull-up |
| R9 | Resistor | 10kΩ | R0603 | Aisler Lovely Lib | Shared RC_OUT pull-down (DRV8214 ready) |
| R_IPF | Resistor | 1.0kΩ | R0603 | Aisler Lovely Lib | Optional IPROPI RC filter series resistor |
| C8 | Ceramic cap | 10µF | C0603 | Aisler Lovely Lib | U4 VM bulk |
| C9 | Ceramic cap | 100nF | C0402 | Aisler Lovely Lib | U4 VM HF |
| C10 | Ceramic cap | 100nF | C0402 | Aisler Lovely Lib | U4 VCC HF |
| C11 | Ceramic cap | 10µF | C0603 | Aisler Lovely Lib | U5 VM bulk |
| C12 | Ceramic cap | 100nF | C0402 | Aisler Lovely Lib | U5 VM HF |
| C13 | Ceramic cap | 100nF | C0402 | Aisler Lovely Lib | U5 VCC HF |
| C14 | Ceramic cap | 10µF | C0603 | Aisler Lovely Lib | U6 VM bulk |
| C15 | Ceramic cap | 100nF | C0402 | Aisler Lovely Lib | U6 VM HF |
| C16 | Ceramic cap | 100nF | C0402 | Aisler Lovely Lib | U6 VCC HF |
| C17 | Ceramic cap | 10µF | C0603 | Aisler Lovely Lib | U7 VM bulk |
| C18 | Ceramic cap | 100nF | C0402 | Aisler Lovely Lib | U7 VM HF |
| C19 | Ceramic cap | 100nF | C0402 | Aisler Lovely Lib | U7 VCC HF |
| C20 | Ceramic cap | 10µF | C0603 | Aisler Lovely Lib | U8 VM bulk |
| C21 | Ceramic cap | 100nF | C0402 | Aisler Lovely Lib | U8 VM HF |
| C22 | Ceramic cap | 100nF | C0402 | Aisler Lovely Lib | U8 VCC HF |
| C23 | Ceramic cap | 10µF | C0603 | Aisler Lovely Lib | U9 VM bulk |
| C24 | Ceramic cap | 100nF | C0402 | Aisler Lovely Lib | U9 VM HF |
| C25 | Ceramic cap | 100nF | C0402 | Aisler Lovely Lib | U9 VCC HF |
| C_IPF | Ceramic cap | 100nF | C0603 | Aisler Lovely Lib | Optional IPROPI RC filter shunt cap |
| SJ_IP_BYP | Solder jumper | 3-pad | PCB jumper | - | IPROPI direct path (default closed) |
| SJ_IP_RC | Solder jumper | 3-pad | PCB jumper | - | IPROPI RC path (default open) |
| J2 | RJ11 5301-4P4C | - | Through-hole | TBD | Motor 1 connector |
| J3 | RJ11 5301-4P4C | - | Through-hole | TBD | Motor 2 connector |
| J4 | RJ11 5301-4P4C | - | Through-hole | TBD | Motor 3 connector |
| J5 | RJ11 5301-4P4C | - | Through-hole | TBD | Motor 4 connector |
| J6 | RJ11 5301-4P4C | - | Through-hole | TBD | Motor 5 connector |
| J7 | RJ11 5301-4P4C | - | Through-hole | TBD | Motor 6 connector |

## Components Removed vs Rev.1

The following components from Rev.1 are **no longer present**:

### Motor Driver Section
- 3x legacy H-bridge driver ICs + 9x decoupling caps
- 2x GAQY212GSX optocouplers
- 1x SN74LVC1G04 inverter + decoupling cap
- 2x 330Ω optocoupler drive resistors
- All MCOM, MNODD, MNEVEN nets removed

### Analog / Current Sensing Section
- INA219AIDR — I2C current sense amplifier
- 100mΩ (R2512) — current sense shunt resistor
- 2x 10Ω — INA219 input filter resistors
- LMV358 — dual op-amp, tacho conditioning
- ~12 resistors — tacho stage, MCOM divider, Vref divider, tuning pads
- ~4 caps — tacho filter/decoupling
- MCOM_SENSE, TACHO nets removed

**Total removed: 2 ICs + 1 shunt + ~17 passives (analog) + 3 ICs + 2 opto + ~12 passives (motor) ≈ 35 components**

## Future Upgrade: DRV8214

DRV8214RTER is pin-compatible with DRV8215RTER (same WQFN-16 3×3mm footprint).
Drop-in replacement that adds hardware ripple counting (sensorless position sensing).
**No PCB change required** — pin 3 (RC_OUT) is already routed to RC_OUT_ALL net with
R9 pull-down and GPIO3 interrupt input. Simply swap ICs and enable RC_EN via I2C register.

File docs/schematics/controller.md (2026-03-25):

# Controller Schematic

## Overview

ESP32-S3 Super Mini module with I2C bus (6x DRV8215 motor drivers + expansion),
UART header, 1-Wire bus supporting 8 probes, circulation pump relay output,
and WS2812 RGB status LED. 5 free GPIOs exposed as solder pads for expansion.
Connects to Power and Motor sections. Rev.2 uses only I2C for motor control,
freeing 8 GPIO compared to Rev.1.

## Block Diagram

```
                        HeatValve-6 Rev.2 : Controller
  ┌───────────────────────────────────────────────────────────────────────┐
  │                                                                       │
  │  ◄── VBUS (from Power) ── D_5V (Schottky) ──┐                        │
  │  ◄── 3V3 (from Power) ────────────────┐ │                        │
  │  ◄── GND ─────────────────────────────────┐│ │                        │
  │                                            ││ │                        │
  │            ┌────────────────────────┐      ││ │                        │
  │            │    ESP32-S3 Super Mini │      ││ │                        │
  │            │        (U_ESP)        │      ││ │                        │
  │            │                        │  5V,GND                        │
  │            │  GPIO1  (IPROPI_ADC)←──│←── IPROPI_BUS (from Motor)      │
  │            │  GPIO2  (nSLEEP)  ────>│──→ nSLEEP_ALL (to Motor, 6x)   │
  │            │  GPIO3  (RC_OUT)  <────│←── RC_OUT_ALL (from Motor, 6x)  │
  │            │  GPIO4  (nFAULT)  <────│←── nFAULT_ALL (from Motor, 6x) │
  │            │                        │                                 │
  │            │  GPIO5  (PUMP_CTRL)───>│──R10(10k)─┐  ┌─────────┐       │
  │            │                        │            Q1 │  K1     │       │
  │            │                        │  D1(1N4148)│  │  Relay  │       │
  │            │                        │  VBUS──┬───┘  │COM NO──│─→J_PUMP│
  │            │                        │        └coil──┘         │       │
  │            │                        │                                 │
  │            │  GPIO9  (I2C_SDA) <──>│──┬── R20 (3.3k)── 3V3 ──────>│─→ Motor: 6x DRV8215
  │            │  GPIO8  (I2C_SCL) ───>│──┤── R21 (3.3k)── 3V3  ┌────┐│
  │            │                        │  └─────────────────│J_I2C││
  │            │  GPIO43 (UART TX) ───>│── R18 (470) ── 3V3 │(1x4)││
  │            │  GPIO44 (UART RX) <───│── R19 (470) ── 3V3 └────┘│
  │            │                        │              ┌────────┐   │
  │            │                        │              │ J_UART │   │
  │            │  GPIO10 (1-Wire)  <──>│── R_OW ── 3V3 │ (1x4)  │   │
  │            │                        │    │          └────────┘   │
  │            │                        │    │  C10  D_1W            │
  │            │                        │    │          ┌──────────┐ │
  │            │                        │    └──────────│  J_1W    │ │
  │            │                        │               │ 8 probes │ │
  │            │  GPIO48 (WS2812)  ───>│──→ [RGB LED]  └──────────┘ │
  │            │                        │   (on module)              │
  │            └────────────────────────┘                            │
  │                    C_ESP1/C_ESP2 (decoupling)                    │
  │                                                                  │
  │  Expansion pads (J_EXP): GND, 3V3, GPIO6, GPIO7,               │
  │                           GPIO11, GPIO12, GPIO13                 │
  │                                                                  │
  └───────────────────────────────────────────────────────────────────────┘

  Connections:  ══> Power section (VBUS via D_5V → ESP32 5V, 3V3 from MT2492 for pull-ups, GND)
                ──> Motor section (I2C_SDA, I2C_SCL, nSLEEP_ALL, nFAULT_ALL, IPROPI_ADC)
                ──> Pump relay (K1 via Q1)
                ──> External headers (J_I2C, J_UART, J_1W)
                ──> Expansion pads (J_EXP: 5 GPIO + GND + 3V3)
```

## ESP32-S3 Super Mini Module (U_ESP)

The ESP32-S3 Super Mini is a pre-built module with onboard USB-C, antenna, flash,
PSRAM, and 3.3V regulator. Powered via 5V pin through a Schottky diode from VBUS.

### Module Power

| Pin | Net | Connection |
|-----|-----|---|
| 5V | VBUS_ESP | ← VBUS via D_5V Schottky diode (~4.7V) |
| 3V3 | - | NOT connected externally (module's onboard LDO generates 3.3V from 5V pin) |
| GND | GND | Ground plane |

### Backfeed Protection Diode

| Ref | Value | Footprint | Net From | Net To | Purpose |
|-----|---|---|---|---|---|
| D_5V | SS14 (1A/40V Schottky) | SMA (DO-214AC) | VBUS | VBUS_ESP (ESP32 5V pin) | Prevents backfeed when module USB-C is connected for programming |

Notes:
- D_5V Schottky diode (~0.3V drop at 200mA) isolates board VBUS from module's onboard USB.
- When both USBs are connected, current cannot flow between the two 5V sources.
- Module's onboard LDO (typically ME6211, min Vin ~3.5V) works fine at ~4.7V.
- 1A rating sufficient for ESP32-S3 peak consumption (~350mA WiFi burst).
- 3V3 (MT2492) powers I2C pull-ups, UART pull-ups, 1-Wire, nFAULT pull-up, and DRV8215 VM+VCC — NOT the ESP32.
- Module's onboard USB-C remains available for programming/debugging.

### GPIO Assignments

| GPIO | Net | Direction | Function | Section |
|---|-----|---|---|---|
| GPIO1 | IPROPI_ADC | IN (ADC) | DRV8215 current sense analog input | Motor |
| GPIO2 | nSLEEP_ALL | OUT | Shared nSLEEP for all 6x DRV8215 | Motor |
| GPIO3 | RC_OUT_ALL | IN (INT) | Shared RC_OUT from all 6x pin 3 (DRV8214 ready, NC on DRV8215) | Motor |
| GPIO4 | nFAULT_ALL | IN | Wired-OR nFAULT from all 6x DRV8215 | Motor |
| GPIO8 | I2C_SCL | OUT | I2C Clock (shared bus) | Motor/Ext |
| GPIO9 | I2C_SDA | I/O | I2C Data (shared bus) | Motor/Ext |
| GPIO10 | ONEWIRE | I/O | 1-Wire bus (8 probes) | Controller |
| GPIO5 | PUMP_CTRL | OUT | Circulation pump relay control | Controller |
| GPIO48 | WS2812_DATA | OUT | Status LED data | Controller |

Notes:
- GPIO6, GPIO7, GPIO11, GPIO12, GPIO13 are **freed** — exposed as solder pads for future expansion.
- GPIO3 allocated for RC_OUT_ALL (DRV8214 ripple count). On DRV8215 boards, R9 pull-down holds it LOW.
- GPIO5 drives circulation pump relay via Q1 MOSFET.
- GPIO1 must be ADC-capable (ESP32-S3: ADC1_CH0).

### GPIO Comparison (Rev.1 → Rev.2)

| GPIO | Rev.1 Function | Rev.2 Function | Change |
|---|---|---|---|
| GPIO1 | spare | **IPROPI_ADC** | New: analog current sense |
| GPIO2 | MOTOR_MUX | **nSLEEP_ALL** | Repurposed: MUX → shared sleep |
| GPIO3 | MOTOR_ENA1 (nSLEEP #2) | **RC_OUT_ALL** | Repurposed: motor enable → RC_OUT (DRV8214 ready) |
| GPIO4 | MOTOR_ENA2 (nSLEEP #3) | **nFAULT_ALL** | Repurposed: motor enable → fault |
| GPIO5 | MOTOR_DIR2 (IN2) | **PUMP_CTRL** | Repurposed: motor dir → pump relay |
| GPIO6 | MOTOR_DIR1 (IN1) | **FREE** | Freed |
| GPIO7 | TACHO (LMV358 output) | **FREE** | Freed |
| GPIO8 | I2C_SCL | I2C_SCL | Unchanged |
| GPIO9 | I2C_SDA | I2C_SDA | Unchanged |
| GPIO10 | ONEWIRE | ONEWIRE | Unchanged |
| GPIO11 | MOTOR_ENA0 (nSLEEP #1) | **FREE** | Freed |
| GPIO12 | spare | **FREE** | Still free |
| GPIO13 | spare | **FREE** | Still free |
| GPIO48 | WS2812_DATA | WS2812_DATA | Unchanged |

**Result: 5 GPIO freed** (GPIO6-7, GPIO11-13). Exposed as solder pads for future expansion.

## I2C Bus

Shared bus for 6x DRV8215 motor drivers and external expansion.

### I2C Pull-up Resistors

| Ref | Value | Footprint | Net From | Net To | Purpose |
|-----|---|---|---|---|---|
| R20 | 3.3kΩ | R0603 | I2C_SDA | 3V3 | SDA pull-up |
| R21 | 3.3kΩ | R0603 | I2C_SCL | 3V3 | SCL pull-up |

Note: DRV8215 datasheet recommends 2.2kΩ pull-ups on A0/A1 address pins (not needed
when pins are tied directly to GND/VCC or left floating). The I2C bus pull-ups at 3.3kΩ
are adequate for the bus length and capacitance in this design (~30pF total with 6 devices).

### I2C External Header (J_I2C)

Standard 2.54mm pin header for external I2C devices (displays, sensors).

| Pin | Net | Description |
|-----|-----|---|
| 1 | GND | Ground |
| 2 | 3V3 | 3.3V supply |
| 3 | I2C_SDA | I2C Data |
| 4 | I2C_SCL | I2C Clock |

Component: 1x4 2.54mm male pin header (C2337)

### I2C Devices on Bus

| Address (7-bit) | Device | Section |
|---|---|---|
| 0x30 | DRV8215 #1 (Motor 1) | Motor |
| 0x31 | DRV8215 #2 (Motor 2) | Motor |
| 0x32 | DRV8215 #3 (Motor 3) | Motor |
| 0x33 | DRV8215 #4 (Motor 4) | Motor |
| 0x34 | DRV8215 #5 (Motor 5) | Motor |
| 0x35 | DRV8215 #6 (Motor 6) | Motor |
| (ext) | Display/sensors | External via J_I2C |

Note: INA219 (Rev.1 address 0x40) is **removed** in Rev.2. Address range 0x40-0x4F
is now free for external devices.

## UART Header (J_UART)

Standard 2.54mm pin header for debug/expansion.

| Pin | Net | Description |
|-----|-----|---|
| 1 | GND | Ground |
| 2 | 3V3 | 3.3V supply |
| 3 | TX (GPIO43) | UART TX |
| 4 | RX (GPIO44) | UART RX |

Component: 1x4 2.54mm male pin header (C2337)

### UART Pull-up Resistors

| Ref | Value | Footprint | Net From | Net To | Purpose |
|-----|---|---|---|---|---|
| R18 | 470Ω | R0603 | UART_TX | 3V3 | TX pull-up |
| R19 | 470Ω | R0603 | UART_RX | 3V3 | RX pull-up |

## 1-Wire Bus (8-Probe Support)

Single 1-Wire bus on GPIO10 with support for 8 Dallas temperature probes.
Each probe needs 3 wires: GND, DATA (1-Wire), VCC (3V3).

### 1-Wire Pull-up

| Ref | Value | Footprint | Net From | Net To | Purpose |
|-----|---|---|---|---|---|
| R_OW | 4.7kΩ | R0603 | ONEWIRE | 3V3 | 1-Wire bus pull-up |

### 1-Wire Connectors (J_1W_A / J_1W_B / J_1W_C)

3× KF350-3P screw terminals (3.5mm pitch). All probes share the same 1-Wire bus —
each terminal provides parallel GND, DATA, VCC for 2-3 probes.

| Ref | Positions | Probes | Pin 1 | Pin 2 | Pin 3 |
|-----|---|---|---|---|---|
| J_1W_A | 3-pin | Probe 1-3 | GND | ONEWIRE | 3V3 |
| J_1W_B | 3-pin | Probe 4-6 | GND | ONEWIRE | 3V3 |
| J_1W_C | 3-pin | Probe 7-8 + spare | GND | ONEWIRE | 3V3 |

All GND, ONEWIRE, and 3V3 pins are connected in parallel on the PCB.
Multiple probe wires can be twisted together and clamped in a single screw position.

| Ref | Component | Footprint | Qty | Purpose |
|-----|---|---|-----|---|
| J_1W_A | KF350-3P | 3.5mm pitch, 3-pin | 1 | Probe 1-3 |
| J_1W_B | KF350-3P | 3.5mm pitch, 3-pin | 1 | Probe 4-6 |
| J_1W_C | KF350-3P | 3.5mm pitch, 3-pin | 1 | Probe 7-8 + spare |

### 1-Wire Decoupling

| Ref | Value | Footprint | Net From | Net To | Purpose |
|-----|---|---|---|---|---|
| C10 | 100nF | C0603 | 3V3 (at J_1W) | GND | 1-Wire power decoupling |

### 1-Wire ESD Protection (optional)

| Ref | Value | Footprint | Net From | Net To | Purpose |
|-----|---|---|---|---|---|
| D_1W | TVS diode | SOD-323 | ONEWIRE | GND | ESD protection for long cable runs |

Notes:
- All 8 probes share the single 1-Wire bus (each DS18B20 has unique ROM ID)
- Maximum cable length ~50m with proper pull-up (4.7kΩ at 3.3V)
- For cable runs >10m, consider lowering R_OW to 2.2kΩ or adding active pull-up
- 100nF decoupling at connector prevents noise injection from probe cables

## Circulation Pump Output

GPIO5 drives a 5V relay via N-channel MOSFET for on/off control of the circulation pump.
Relay provides galvanic isolation — no mains voltage on the PCB.

### Circuit

```
 GPIO5 ──┬── Q1 Gate (2N7002)      K1 Relay
         │                          ┌─────────┐
       R10(10kΩ)                    │ ┌─┐     │
         │          Q1 Drain ──────→│ │ │coil  │──→ VBUS (5V)
        GND         Q1 Source ─→ GND│ └─┘     │
                                    │  ↑ D1   │
                    D1 anode ──────→│  │flyback│
                    D1 cathode ────→│──┘      │
                                    │         │
                                    │ COM ●───│──→ J_PUMP pin 1
                                    │ NO  ●───│──→ J_PUMP pin 2
                                    └─────────┘
```

### Components

| Ref | Value | Footprint | Net From | Net To | Purpose |
|-----|---|---|---|---|---|
| Q1 | 2N7002 (N-ch MOSFET) | SOT-23 | GPIO5 (gate) | K1 coil (drain) | Low-side relay driver |
| R10 | 10kΩ | R0603 | Q1 gate | GND | Gate pull-down — keeps pump OFF during ESP32 boot/reset |
| D1 | 1N4148 | SOD-323 | Q1 drain (anode) | VBUS (cathode) | Flyback protection for relay coil |
| K1 | 5V SPST-NO relay | Through-hole | VBUS → coil → Q1 drain | COM/NO → J_PUMP | Pump switching (galvanic isolation) |
| J_PUMP | KF350-2P screw terminal | 3.5mm pitch, 2-pin | K1 COM | K1 NO | Pump wire connection (dry contact) |

Notes:
- 2N7002 Vgs(th) ~1.0–2.5V — fully on at 3.3V GPIO drive. Rdson ~2Ω at Vgs=2.5V.
- Relay coil current 40mA from VBUS (5V). Well within 2N7002's 300mA rating.
- R10 pull-down ensures relay stays OFF while ESP32 GPIO is floating (boot, deep sleep, reset).
- D1 clamps inductive kickback from relay coil when Q1 turns off.
- J_PUMP (KF350-2P) provides dry contact output (COM + NO) — screw pump wires directly in.
- For 230V AC pumps: wire through external contactor or use relay contacts directly (check relay rating).
- Relay contacts (G5NB-1A-E-DC5V) rated 5A/250VAC. Keep creepage/clearance and safety rules for mains wiring.

### Relay Selection

| Parameter | Value |
|---|---|
| Part | G5NB-1A-E-DC5V (OMRON) |
| LCSC | C48746 |
| Coil voltage | 5VDC |
| Coil resistance | 125Ω (40mA, 200mW) |
| Contact config | SPST-NO |
| Contact rating | 5A/250VAC |
| Footprint | Through-hole, 20.4 × 7mm |
| Certifications | UL/CSA/VDE, EN61010 reinforced insulation |

## GPIO Expansion Pads

Unpopulated solder pads exposing 5 free GPIOs plus power for future use.
Pads are 2.54mm pitch, compatible with standard pin headers if needed later.

### Pad Layout

| Pad | Net | Description |
|-----|-----|---|
| 1 | GND | Ground |
| 2 | 3V3 | 3.3V supply |
| 3 | GPIO6 | Free GPIO (ADC/touch capable) |
| 4 | GPIO7 | Free GPIO (ADC/touch capable) |
| 5 | GPIO11 | Free GPIO |
| 6 | GPIO12 | Free GPIO |
| 7 | GPIO13 | Free GPIO |

Notes:
- Solder pads only — no headers populated. Solder wires or pin headers as needed.
- All GPIOs are directly connected to ESP32-S3 with no series resistors or protection.
- Possible uses: I2C display, extra sensors, external buttons, analog input, PWM output.
- GND + 3V3 pads provide power for whatever is connected.

## WS2812 Status LED

On-module WS2812 connected to GPIO48. No external components needed.

### Status LED Color Codes

| Color | Pattern | Meaning |
|---|---|---|
| Green | Solid | Normal, connected to HA |
| Green | Breathing | Standalone mode |
| Blue | Flashing | Booting / WiFi connecting |
| Cyan | Solid | Motor running |
| Yellow | Solid | Warning (sensor offline) |
| Orange | Flashing | No 1-Wire sensors |
| Red | Solid | Error (API disconnected) |
| Red | Flashing | Critical (stall/overcurrent) |
| Purple | Solid | Calibration in progress |
| White | Flash | Command received |

## 3V3 Local Decoupling

| Ref | Value | Footprint | Net From | Net To | Purpose |
|-----|---|---|---|---|---|
| C_ESP1 | 100nF | C0603 | 3V3 (controller area) | GND | HF decoupling for I2C/UART/1-Wire pull-ups |
| C_ESP2 | 10µF | C0603 | 3V3 (controller area) | GND | Bulk decoupling for local 3V3 loads |

Note: ESP32 module has its own onboard decoupling on 5V input and internal 3.3V rail.
3V3 is supplied by the MT2492 buck converter (single rail for all 3.3V loads).

## Connections to Other Sections

### → Power Section
- VBUS → D_5V → ESP32 5V pin (module power)
- 3V3 (I2C/UART/1-Wire pull-ups, nFAULT pull-up, DRV8215 VM+VCC, local decoupling)
- GND

### → Motor Section (via I2C + 4 GPIO)
- I2C_SDA (GPIO9) ↔ 6x DRV8215 SDA pins
- I2C_SCL (GPIO8) → 6x DRV8215 SCL pins
- nSLEEP_ALL (GPIO2) → 6x DRV8215 nSLEEP pins (shared wake/sleep)
- RC_OUT_ALL (GPIO3) ← 6x DRV8215 pin 3 (wire-OR, DRV8214 ripple count ready)
- nFAULT_ALL (GPIO4) ← 6x DRV8215 nFAULT pins (wired-OR, open-drain)
- IPROPI_ADC (GPIO1) ← shared R7 voltage (analog current sense)

### → Pump
- PUMP_CTRL (GPIO5) → Q1 gate → K1 relay → J_PUMP screw terminal (dry contact)

### → Expansion Pads (J_EXP)
- 5 free GPIOs (GPIO6, GPIO7, GPIO11, GPIO12, GPIO13) + GND + 3V3
- Unpopulated solder pads — solder headers or wires as needed

## BOM Summary (Controller Section)

| Ref | Component | Value | Footprint | LCSC | Category |
|-----|---|---|---|---|---|
| U_ESP | ESP32-S3 Super Mini | Module | - | - | Manual |
| D_5V | Schottky diode | SS14 (1A/40V) | SMA (DO-214AC) | C2480 | Basic |
| Q1 | N-ch MOSFET | 2N7002 | SOT-23 | C8545 | Basic |
| R10 | Resistor | 10kΩ | R0603 | C25804 | Basic |
| R18 | Resistor | 470Ω | R0603 | C23179 | Basic |
| R19 | Resistor | 470Ω | R0603 | C23179 | Basic |
| R20 | Resistor | 3.3kΩ | R0603 | TBD | Basic |
| R21 | Resistor | 3.3kΩ | R0603 | TBD | Basic |
| R_OW | Resistor | 4.7kΩ | R0603 | C23162 | Basic |
| D1 | Switching diode | 1N4148 | SOD-323 | C81598 | Basic |
| C10 | Ceramic cap | 100nF | C0603 | C14663 | Basic |
| C_ESP1 | Ceramic cap | 100nF | C0603 | C14663 | Basic |
| C_ESP2 | Ceramic cap | 10µF | C0603 | TBD | Basic |
| D_1W | TVS diode (opt) | PESD1CAN | SOD-323 | TBD | TBD |
| K1 | Relay | G5NB-1A-E-DC5V (OMRON) | TH 20.4×7mm | C48746 | Basic |
| J_I2C | Pin header | 1x4 | 2.54mm | C2337 | Basic |
| J_UART | Pin header | 1x4 | 2.54mm | C2337 | Basic |
| J_PUMP | Screw terminal | KF350-3.5-2P | 3.5mm pitch | C474892 | Basic |
| J_1W_A | Screw terminal | KF350-3.5-3P | 3.5mm pitch | C474893 | Basic |
| J_1W_B | Screw terminal | KF350-3.5-3P | 3.5mm pitch | C474893 | Basic |
| J_1W_C | Screw terminal | KF350-3.5-3P | 3.5mm pitch | C474893 | Basic |
| J_EXP | Solder pads | 7-pad | 2.54mm | - | PCB |

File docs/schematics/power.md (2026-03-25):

# Power Supply Schematic

## Overview

USB-C input with 2× 5.1kΩ on CC1/CC2 to GND (sink signature). Delivers 5V from any USB-C source (PD or non-PD) without a PD controller.
Two power paths: VBUS → MT2492 → 3V3 (all 3.3V loads), VBUS → ESP32 (via Schottky diode).
LED on 3V3 (power indicator). ESP32 power indicated by module LEDs.

## Block Diagram

```
                          HeatValve-6 Rev.2 : Power Supply
  ┌─────────────────────────────────────────────────────────────────────┐
  │                                                                     │
  │  USB-C (J1)  CC1,CC2 ──→ R1,R2 (5.1k to GND)                  │
  │       VBUS ───────────────┬──→ C1,C2 --──────┬──→ MT2492 (U3) ──→ 3V3 ══> All 3.3V loads
  │                           │                  │    (Sync Buck)   │   (DRV8215 VM+VCC,
  │                           │                  │    C3,C4 L1 C5,C6 │   I2C, 1-Wire, UART
  │                           │                  │    R3,R4 (FB)    │   pull-ups, nFAULT)
  │                           │                  │                  │  LED_PWR, R6
  │                           │                  │                  │
  │                           │                  └──→ D_5V (Schottky) ──→ VBUS_ESP ══> ESP32 5V pin
  │                           │                       (~0.3V drop → ~4.7V)     (module's LDO → 3.3V)
  │  GND ═══════════════════════════════════════════════════════════════╧══════> GND plane
  │                                                                     │
  └─────────────────────────────────────────────────────────────────────┘

  Signal flow: USB-C (5V) → VBUS → MT2492 → 3V3 (motors, logic, peripherals)
                                    → D_5V → ESP32 5V pin (~4.7V)
```

## Power Rails

| Rail | Voltage | Source | Purpose |
|---|---|---|---|
| VBUS | 5V | USB-C (J1) direct | Main input rail |
| VBUS_ESP | ~4.7V | VBUS via D_5V (Schottky) | ESP32 module 5V pin (module's LDO → 3.3V) |
| 3V3 | 3.3V | MT2492 (synchronous switching) | 6x DRV8215 VM+VCC, I2C/UART/1-Wire pull-ups, nFAULT pull-up |

## Net List

### USB-C Connector (J1)

| Pin | Net | Description |
|-----|-----|---|
| VBUS | VBUS | USB 5V power |
| CC1 | CC1 | Configuration channel 1 |
| CC2 | CC2 | Configuration channel 2 |
| D+  | D+ | USB data (to ESP32 via module) |
| D-  | D- | USB data (to ESP32 via module) |
| GND | GND | Ground |
| SHIELD | GND | Shield to ground |

Component: GT-USB-7010ASV (C2988369) or DEALON USB-TYPE-C-006 (C2927026) for 6-pin power-only.

### USB-C Sink Signature (CC pull-down)

| Ref | Value | Footprint | Net From | Net To | Purpose |
|-----|---|---|---|---|---|
| R1 | 5.1kΩ | R0603 | CC1 (J1) | GND | Sink signature; source supplies 5V |
| R2 | 5.1kΩ | R0603 | CC2 (J1) | GND | Sink signature (both CC for plug orientation) |

Notes:
- 2× 5.1kΩ (Ra per USB Type-C) identifies the board as a 5V sink. Works with PD and non-PD sources; PD sources default to 5V when no PD negotiation occurs.
- D+/D- on J1 can be NC for power-only use.

### USB-C Input Filter

| Ref | Value | Footprint | Net From | Net To | Purpose |
|-----|---|---|---|---|---|
| C1 | 10uF | C0603 | VBUS | GND | VBUS LF decoupling near connector |
| C2 | 100nF | C0603 | VBUS | GND | VBUS HF decoupling near connector |

### MT2492 Synchronous Switching Regulator - 3V3 (U3)

Signal flow: **+5V → IN (5)** (with 10µF); **EN (4)** via 100kΩ to +5V; **BS (1) – 22nF – SW (6)**; **SW (6) → L1 (4.7µH) → 22µF + 22µF → 3V3**; **FB (3)**: R3 (115kΩ) from 3V3 to FB, R4 (25.5kΩ) from FB to GND.

| Pin | Net | Component/Connection |
|-----|-----|---|
| 1 (BS) | BS | ← 22nF (C3) to SW (6) |
| 2 (GND) | GND | Ground |
| 3 (FB) | FB | R3 (115kΩ) ← 3V3; R4 (25.5kΩ) → GND |
| 4 (EN) | EN | ← VBUS via R5 (100kΩ) |
| 5 (IN) | VBUS | Input supply; 10µF (C4) to GND |
| 6 (SW) | SW | → L1 (4.7µH) → 3V3 (C5, C6 output) |

Component: MT2492, SOT-23-6 ([C89358](https://www.lcsc.com/datasheet/C89358.pdf)), XI'AN Aerosemi Tech

Key specs:
- Input: 4.5V - 16V
- Output: 2A max
- Switching frequency: 600kHz
- Efficiency: up to 96%
- Synchronous rectification (no external Schottky diode needed)
- PWM/PFM auto-mode switching
- Overcurrent protection with hiccup mode
- Thermal shutdown

### MT2492 Support Components

| Ref | Value | Footprint | Net From | Net To | Purpose |
|-----|---|---|---|---|---|
| C3 | 22nF | C0603 | BS (U3.1) | SW (U3.6) | Bootstrap cap |
| C4 | 10µF | C0603 | VBUS (U3.5 IN) | GND | Input decoupling |
| C5 | 22µF | C0805 | 3V3 | GND | Output bulk |
| C6 | 22µF | C0805 | 3V3 | GND | Output bulk |
| L1 | 4.7µH | 4x4mm or 6x6mm | SW (U3.6) | 3V3 | Buck inductor (≥2A sat) |
| R3 | 115kΩ | R0603 | 3V3 | FB (U3.3) | Feedback upper |
| R4 | 25.5kΩ | R0603 | FB (U3.3) | GND | Feedback lower |
| R5 | 100kΩ | R0603 | VBUS | EN (U3.4) | Enable pull-up |

Notes:
- **No Schottky diode needed** – MT2492 has internal synchronous MOSFET.
- Feedback: Vout = 0.6V × (1 + R3/R4) → 115k / 25.5k ≈ 3.31V.
- Bootstrap C3: 22nF between BS (1) and SW (6).
- L1: 4.7µH, ≥2A saturation current, low DCR.
  Recommended: Würth 744043004R7 (4x4mm, 2.4A, Aisler Lovely Library compatible)
  Alternative: Sunlord SWPA4030S4R7MT (4x3mm, 2A) or SWPA6045S4R7MT (6x6mm, 3A)

### Bulk Input Capacitor

| Ref | Value | Footprint | Net From | Net To | Purpose |
|-----|---|---|---|---|---|
| C7 | 220µF | SMD electrolytic 6.3mm | VBUS | GND | Bulk storage |

Notes:
- 220µF bulk + C1 (10µF) + C4 (10µF) + C2 (100nF) = ~240µF total on VBUS.
- Sufficient for motor startup transients (300mA peak) and ESP32 WiFi bursts (~350mA).
- MT2492 responds within ~10µs (600kHz switching): ΔV = 0.5A × 10µs / 240µF ≈ 21mV ripple.
- No separate bulk needed on 3V3 — output ceramics C5+C6 (2×22µF = 44µF) are adequate.
- C1 (10µF) + C2 (100nF) at USB-C connector provide local VBUS decoupling.
- 220µF avoids USB-C inrush issues (940µF could trip some USB sources on plug-in).

### ESP32 Backfeed Protection Diode (D_5V)

| Ref | Value | Footprint | Net From | Net To | Purpose |
|-----|---|---|---|---|---|
| D_5V | SS14 (1A/40V Schottky) | SMA (DO-214AC) | VBUS | VBUS_ESP (ESP32 5V pin) | Backfeed protection |

Notes:
- Schottky diode (~0.3V forward drop at 200mA) isolates board VBUS from ESP32 module's onboard USB-C.
- When programming via module USB while board is powered, current cannot backfeed between USB sources.
- ~4.7V is sufficient for module's onboard LDO (min Vin typically ~3.5V).
- 1A rating sufficient for ESP32-S3 peak consumption (~350mA WiFi burst). LCSC C2480 (Basic part).

### Power LED (3V3)

| Ref | Value | Footprint | Net From | Net To | Purpose |
|-----|---|---|---|---|---|
| LED_PWR | Green LED | 0603 | 3V3 | R6 | 3V3 rail power indicator |
| R6 | 1kΩ | R0603 | LED_PWR.K | GND | LED current limiter (~1.5mA) |

Notes:
- LED_PWR indicates 3V3 is present (MT2492 up); lights as soon as rail is active.
- Green LED at 1kΩ draws ~1.5mA (dim but visible, low power).
- ESP32 power: indicated by module's onboard LEDs.

## Power Sequencing

1. USB-C connected → source detects sink (5.1kΩ on CC) → VBUS rises to 5V
2. MT2492 starts → 3V3 available (~1ms); LED_PWR lights; DRV8215 VM+VCC, pull-ups, nFAULT powered
3. VBUS → D_5V → ESP32 5V pin (~4.7V) → module's onboard LDO → 3.3V → ESP32 boots

## Design Notes

- 2× 5.1kΩ on CC1/CC2 to GND: simple USB Type-C sink (Ra). Delivers 5V from any USB-C source (PD or non-PD) without a PD controller on the board. **PD chargers (sources with PD controller) are supported:** they detect the sink and supply default 5V when no PD negotiation occurs. No 9V/12V/20V request possible.
- ESP32 powered via VBUS through D_5V Schottky diode (~4.7V on module's 5V pin). Module's onboard LDO generates 3.3V for the ESP32.
- **Single 3V3 rail** from MT2492 buck converter supplies all 3.3V loads: 6x DRV8215 (VM and VCC tied together), I2C/UART/1-Wire pull-ups, nFAULT pull-up. No separate LDO needed — Rev.1's AMS1117 was required for noise-sensitive INA219/LMV358 analog circuits, which are removed in Rev.2.
- MT2492 (synchronous switching) provides efficient high-current 3V3 (96% efficiency, 2A capacity). Peak load ~315mA (300mA motor + 15mA logic/pull-ups).
- Both paths fed from VBUS, independent.
- D_5V prevents backfeed when programming via module's onboard USB-C while board is powered.

## BOM Summary (Power Section)

| Ref | Component | Value | Footprint | LCSC | Category |
|-----|---|---|---|---|---|
| J1 | USB-C connector | GT-USB-7010ASV or USB-TYPE-C-006 | USB-C / 6-pin | C2988369 / C2927026 | - |
| D_5V | Schottky diode | SS14 (1A/40V) | SMA (DO-214AC) | C2480 | Basic |
| U3 | Sync. switching reg. | MT2492 | SOT-23-6 | C89358 | - |
| L1 | Inductor | 4.7µH | 4x4mm SMD | TBD | TBD |
| LED_PWR | Green LED | 0603 | 0603 | TBD | TBD |
| C1 | Ceramic cap | 10µF | C0603 | TBD | Basic |
| C2 | Ceramic cap | 100nF | C0603 | C14663 | Basic |
| C3 | Ceramic cap | 22nF | C0603 | C21122 | Basic |
| C4 | Ceramic cap | 10µF | C0603 | TBD | Basic |
| C5 | Ceramic cap | 22µF | C0805 | C45783 | Basic |
| C6 | Ceramic cap | 22µF | C0805 | C45783 | Basic |
| C7 | Electrolytic | 220µF | 6.3mm | TBD | Extended |
| R1 | Resistor | 5.1kΩ | R0603 | C23186 | Basic |
| R2 | Resistor | 5.1kΩ | R0603 | C23186 | Basic |
| R3 | Resistor | 115kΩ | R0603 | C22783 | Basic |
| R4 | Resistor | 25.5kΩ | R0603 | C22920 | Basic |
| R5 | Resistor | 100kΩ | R0603 | C25803 | Basic |
| R6 | Resistor | 1kΩ | R0603 | C21190 | Basic |

## Aisler.net Assembly Notes

Aisler's "Amazing Assembly" service sources components from worldwide distributors
(Mouser, Digi-Key, Farnell, Arrow, LCSC). Upload your KiCad project with proper
MPN (Manufacturer Part Number) in the BOM for automatic pricing and sourcing.

### Aisler Lovely Library Compatible Parts (preferred)

These parts are from Würth Elektronik / Diotec and are in Aisler's curated library
(eligible for PCBA discounts):

| Component | Lovely Library Part | MPN | Notes |
|---|---|-----|---|
| L1 (inductor) | Würth WE-TPC | 744043004R7 | 4.7µH, 4x4mm, 2.4A |
| LED_PWR (green) | Würth WL-SMCW | 150060GS75000 | 0603 green LED |
| R1-R6 | Würth CRCW0603 | various | 0603 resistors |
| C (0603 MLCC) | Würth WCAP-CSGP | various | 0603 ceramics |
| C (0805 MLCC) | Würth WCAP-CSGP | various | 0805 ceramics |
| Pin headers | Würth WR-PHD | 61300411121 | 2.54mm male headers |

### Globally Sourced Parts (via Aisler's distributor network)

| Component | MPN | Manufacturer | Source |
|---|-----|---|---|
| MT2492 | MT2492 | Aerosemi | LCSC (C89358) |
| DRV8215 | DRV8215RTER | Texas Instruments | Mouser/Digi-Key |
| GT-USB-7010ASV | GT-USB-7010ASV | G-Switch | LCSC (C2988369) |

### KiCad Project Setup

Install Aisler Lovely Library via KiCad PCM:
1. Open Plugin and Content Manager (PCM)
2. Add package server: https://packages.aisler.net
3. Install "Lovely Library" from Libraries tab
4. Use `PCM_` prefixed symbols for Aisler-optimized parts

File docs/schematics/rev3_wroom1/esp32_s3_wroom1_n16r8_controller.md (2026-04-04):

# ESP32-S3-WROOM-1-N16R8 Controller Schematic (Rev3)

This is a complete schematic specification for replacing ESP32-S3 Super Mini with ESP32-S3-WROOM-1-N16R8 on the HeatValve controller PCB.

Design intent:
- Use ESP32 native USB (USB-C connector on base PCB).
- Keep all inter-sheet connections as netlabels on ESP32 pins.
- Keep ESP-local support circuitry explicit (decoupling, EN/BOOT, USB-C, ESD, pull resistors).
- Use DRV8213 motor drivers (GPIO-controlled H-bridge, no I2C control plane).
- Keep one dedicated I2C bus for display and expansion (I2C_AUX).

## 1. Recommended Sheet Structure

- Sheet A: ESP32 Core (module + EN/BOOT + strapping + decoupling + crystal not needed)
- Sheet B: USB-C + Protection + Native USB D+/D-
- Sheet C: Motor Interface (DRV8213 control nets + nSLEEP + nFAULT)
- Sheet D: Aux Interface (I2C_AUX + display/expansion headers)
- Sheet E: 1-Wire + Pump + Status LED + UART header

Use global netlabels for all nets crossing sheets.

## 2. Netlabels (Global)

Power:
- +5V_USB
- +3V3
- GND

ESP control:
- ESP_EN
- ESP_BOOT

USB:
- USB_D+
- USB_D-
- USB_CC1
- USB_CC2
- USB_SHIELD

I2C bus (aux):
- I2C_AUX_SCL
- I2C_AUX_SDA

Motor logic:
- MOTOR_nSLEEP_ALL
- MOTOR_nFAULT_ALL
- M1_IN1
- M1_IN2
- M2_IN1
- M2_IN2
- M3_IN1
- M3_IN2
- M4_IN1
- M4_IN2
- M5_IN1
- M5_IN2
- M6_IN1
- M6_IN2

Other I/O:
- ONEWIRE_BUS
- PUMP_CTRL
- WS2812_DATA
- UART_TX_DBG
- UART_RX_DBG
- SAFE_IN_1
- AUX_OD_OUT

## 3. ESP32-S3-WROOM-1-N16R8 Connections

U1 = ESP32-S3-WROOM-1-N16R8

Important:
- Keep antenna end outside copper under-module keepout area (all layers).
- Place decoupling capacitors close to U1 3V3 pins.
- Use only netlabels from U1 pins to non-local circuitry.

### 3.1 Power Pins

- U1 3V3 pins -> +3V3
- U1 GND pins -> GND

Decoupling (local, place next to module):
- C101 = 100nF, +3V3 to GND
- C102 = 100nF, +3V3 to GND
- C103 = 1uF, +3V3 to GND
- C104 = 10uF, +3V3 to GND

## 4. EN / BOOT / Reset Circuit

### 4.1 Enable (Reset)

- U1 EN pin -> net ESP_EN
- R101 = 10k, ESP_EN to +3V3 (pull-up)
- C105 = 100nF, ESP_EN to GND
- SW1 RESET pushbutton: ESP_EN to GND (momentary)

### 4.2 Boot Strap

- U1 GPIO0 pin -> net ESP_BOOT
- R102 = 10k, ESP_BOOT to +3V3 (pull-up)
- SW2 BOOT pushbutton: ESP_BOOT to GND (momentary)

### 4.3 Optional Auto-Program Header

If adding USB-UART auto program support:
- 1x6 tag-connect or pin header:
  - +3V3, GND, UART_TX_DBG, UART_RX_DBG, DTR, RTS
- DTR/RTS -> standard ESP auto-program transistor network -> ESP_BOOT/ESP_EN

If not needed, omit DTR/RTS network and keep only SW1/SW2.

## 5. USB-C (Native USB)

### 5.1 USB-C Receptacle

J1 = USB Type-C receptacle (USB2.0)

Connections:
- J1 VBUS -> +5V_USB via F1
- J1 GND -> GND
- J1 SHIELD -> USB_SHIELD
- J1 CC1 -> USB_CC1
- J1 CC2 -> USB_CC2
- J1 D+ pins shorted together -> USB_D+
- J1 D- pins shorted together -> USB_D-

### 5.2 USB-C Sink Signature

- R111 = 5.1k, USB_CC1 to GND
- R112 = 5.1k, USB_CC2 to GND

### 5.3 Input Protection (Recommended)

- F1 = resettable polyfuse, 500mA to 1A hold, between J1 VBUS and +5V_USB
- D111 = TVS 5V, +5V_USB to GND (close to J1)
- U111 = USB ESD array (low capacitance):
  - Protect USB_D+
  - Protect USB_D-
  - Protect CC lines if selected part supports it

### 5.4 USB Data to ESP32

- U1 GPIO20 -> net USB_D+
- U1 GPIO19 -> net USB_D-

Routing rules:
- Keep D+/D- as a tight pair, short and symmetric.
- Avoid stubs and via count mismatch.
- Keep away from switching inductor and motor switching traces.

## 6. Motor Control and I2C Assignment

### 6.1 DRV8213 Motor Control (No I2C)

DRV8213 is controlled by logic inputs, so motor control is GPIO-based.

Assumed topology for 6 valves:
- 6x DRV8213 devices
- Each DRV8213 controls 1 motor (single H-bridge)

Shared motor control nets:
- MOTOR_nSLEEP_ALL (optional shared enable)
- MOTOR_nFAULT_ALL (wired-OR fault back to ESP input, with pull-up)

Per-valve control nets:
- M1_IN1, M1_IN2
- M2_IN1, M2_IN2
- M3_IN1, M3_IN2
- M4_IN1, M4_IN2
- M5_IN1, M5_IN2
- M6_IN1, M6_IN2

Recommended signal conditioning:
- 33R to 100R series resistor near ESP pin on each INx net
- 10k pull-down on each INx net at driver side for known power-up state

Optional current-sense nets:
- M1_IPROPI, M2_IPROPI, M3_IPROPI, M4_IPROPI, M5_IPROPI, M6_IPROPI
- If MCU ADC channels are limited, route IPROPI lines through an analog mux and expose one net to ADC (for example IPROPI_MUX_OUT)

### 6.2 I2C_AUX (Display + Expansion)

- U1 GPIO17 -> I2C_AUX_SCL
- U1 GPIO18 -> I2C_AUX_SDA
- U1 GPIO47 -> PUMP_CTRL

Pull-ups:
- R123 = 3.3k, I2C_AUX_SCL to +3V3
- R124 = 3.3k, I2C_AUX_SDA to +3V3

Display/expansion header (J_AUX_I2C, 1x4):
- Pin 1 GND
- Pin 2 +3V3
- Pin 3 I2C_AUX_SDA
- Pin 4 I2C_AUX_SCL

## 7. Control I/O Mapping (DRV8213 Revision)

Use netlabels only at U1 pins for non-local circuits.

- U1 GPIO1  -> M1_IN1
- U1 GPIO2  -> M1_IN2
- U1 GPIO3  -> M2_IN1
- U1 GPIO4  -> M2_IN2
- U1 GPIO5  -> M3_IN1
- U1 GPIO6  -> M3_IN2
- U1 GPIO7  -> M4_IN1
- U1 GPIO8  -> M4_IN2
- U1 GPIO9  -> M5_IN1
- U1 GPIO10 -> M5_IN2
- U1 GPIO11 -> M6_IN1
- U1 GPIO12 -> M6_IN2
- U1 GPIO13 -> MOTOR_nSLEEP_ALL
- U1 GPIO14 -> MOTOR_nFAULT_ALL
- U1 GPIO15 -> ONEWIRE_BUS
- U1 GPIO16 -> SAFE_IN_1
- U1 GPIO17 -> I2C_AUX_SCL
- U1 GPIO18 -> I2C_AUX_SDA
- U1 GPIO21 -> AUX_OD_OUT
- U1 GPIO43 -> UART_TX_DBG
- U1 GPIO44 -> UART_RX_DBG
- U1 GPIO48 -> WS2812_DATA

Recommended extra I/O use:
- Keep one spare test pad net (for example GPIO47_SPARE) for future expansion

## 8. Suggested External Protection/Conditioning

### 8.1 1-Wire

- R131 = 4.7k, ONEWIRE_BUS to +3V3
- D131 = TVS (optional), ONEWIRE_BUS to GND
- C131 = 100nF from +3V3 to GND near connector

### 8.2 nFAULT and Motor INx Lines

- nFAULT line pull-up on logic side (wired-OR open-drain)
- Optional RC filter on MOTOR_nFAULT_ALL if noise is observed
- Optional series resistor 33R to 100R near ESP pin on each INx line

### 8.3 SAFE_IN_1

- R141 = 10k pull-up to +3V3
- C141 = 100nF to GND
- Optional 1k series into GPIO16
- Optional ESD diode to GND for external connector usage

## 9. Strapping and Pin Safety Notes

- Do not attach heavy external loads to GPIO0, GPIO45, GPIO46.
- Ensure GPIO0 stays high at boot except when BOOT button is pressed.
- Avoid forcing undefined levels on strapping pins during power-up.
- Keep EN RC values as listed to avoid unstable boot.

## 10. Power Topology for WROOM Module

Because WROOM-1-N16R8 is a bare RF module (not dev board):
- Feed U1 directly with +3V3 from board regulator.
- Do not route +5V_USB directly to U1 power pins.
- Keep regulator and decoupling sized for Wi-Fi bursts.

Recommended minimum:
- 3V3 regulator continuous >= 600mA (1A preferred margin)
- Local bulk near U1: 10uF + 1uF + 2x100nF

## 11. EasyEDA NetPort Pin List (Quick Copy)

U1 pins should be labeled with these nets:
- EN          -> ESP_EN
- GPIO0       -> ESP_BOOT
- GPIO19      -> USB_D-
- GPIO20      -> USB_D+
- GPIO1       -> M1_IN1
- GPIO2       -> M1_IN2
- GPIO3       -> M2_IN1
- GPIO4       -> M2_IN2
- GPIO5       -> M3_IN1
- GPIO6       -> M3_IN2
- GPIO7       -> M4_IN1
- GPIO8       -> M4_IN2
-

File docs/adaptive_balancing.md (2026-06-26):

# Adaptive Hydraulic Balancing (room-temperature feedback, no return probes)

## Goal

Replace return-temperature-based balancing with a **self-learning balance** that uses
only signals the board already has reliably:

- the **static hydraulic model** (per-zone area, pipe spacing/type, heat loss → design flow)
  as the starting estimate, and
- **room-temperature control performance** (how well each zone holds its setpoint) as the
  slow correction term.

This is the way the Homematic IP **Falmot-C12** balances: continuous (0–100 %) motorized
valves modulated so that loops reach setpoint together, with per-channel openings adapted
from observed room behaviour — **no flow meters, no return-temperature sensors**. HV6
already has the continuous valves and the room sensors; this change adds the adaptive outer
loop.

Return probes are deliberately **out of scope** here. The manifold supply/return pair (and
any per-loop return probes) remain available for diagnostics only and are not an input to
this controller.

## Why room-temperature feedback is sufficient (and ΔT is not)

At UFH temperatures the per-loop ΔT is ~3–7 °C, so a ±0.5 °C probe is 10–20 % of the whole
signal — too noisy to balance on. The **room sensor**, by contrast, is the quantity we
actually care about and is already used for control. If two comparable rooms need very
different valve openings to hold setpoint — or one chronically lags while wide open — that
*is* the hydraulic imbalance, observed directly at the output instead of inferred from a
marginal ΔT.

## Current code (what this builds on)

Per control cycle (`Hv6ZoneController::control_cycle_`, ~10 s) the inner loop computes, per
zone *i*:

```
raw_i      = compute_raw_position_(i, temp_i, setpoint_i)   // TANH/LINEAR/PID
target_i   = apply_hydraulic_balance_(i, raw_i)             // raw_i * balance_factors_[i]
```

`balance_factors_[i]` is produced by `recalculate_balance_factors_()`
([hv6_zone_controller.cpp](../components/hv6_zone_controller/hv6_zone_controller.cpp)):

- **Static path** — `calculate_hydraulic_outputs_()` derives a design flow
  `V_i = (area_i · heat_loss_i) / (ΔT · 1.163)` and the normalized factor
  `balance_factors_[i] = V_i / max_j V_j` (≤ 1, the highest-flow loop is the reference).
  Note `pipe_correction_factor_()` / `floor_correction_factor_()` are defined
  ([:1498](../components/hv6_zone_controller/hv6_zone_controller.cpp#L1498),
  [:1505](../components/hv6_zone_controller/hv6_zone_controller.cpp#L1505)) but **not used**
  in this path — pipe length only drives the over-length warning. §1a wires them in.
- **Dynamic path** (`dynamic_balancing_enabled`) — overwrites the factor from measured
  flow−return ΔT. **This path is what we are replacing.**

The change makes the static model resistance-aware (the *prior*) and adds a learned
room-temp correction on top.

## Design

### 1. Factor decomposition

Split the per-zone factor into a static prior and a learned correction:

```
balance_factors_[i] = clamp( static_factor_i × adapt_i , 0 , 1 )
```

- `static_factor_i` — recomputed fresh from config (§1a). It carries the *engineering
  estimate* from the numbers the user can supply and reacts immediately to config edits.
- `adapt_i` — the **learned** multiplier, starts at `1.0`, drifts slowly from room-temp
  feedback, clamped to `[adapt_min, adapt_max]` (default `0.5 … 1.5`).

Only `adapt_i` is learned/persisted; `static_factor_i` is always derived fresh from config,
so a pipe/area edit is never overwritten by stale learning — it just re-seeds the prior the
correction rides on.

**Cold start = the static prior.** On a fresh board (or after a balancing reset)
`adapt_i = 1.0`, so `balance_factors_[i] = static_factor_i` from cycle one. The valves do
**not** open equally — they open *unequally*, scaled by each loop's modelled flow need and
resistance (normalized so the most-demanding loop = 1.0 and the rest are throttled below it).
Equal openings only occur if every zone is genuinely identical. The adaptive loop then only
corrects the *residual* the static model couldn't see (actual installed pipe, screed
coverage, furniture, manifold port differences) — it is a refinement, never the only line of
defence.

### 1a. Static prior — resistance-aware, from the numbers a user can find

Today's static factor is **demand-only**: `flow_i = area_i · heat_loss_i / (ΔT · 1.163)`,
then `static_factor_i = flow_i / max_j flow_j` ([:1294](../components/hv6_zone_controller/hv6_zone_controller.cpp#L1294)).
It gives each loop the flow its *heat demand* needs but ignores hydraulic *resistance* — a
long, thin loop flows less than a short one at the same opening — even though
`pipe_correction_factor_()` and `floor_correction_factor_()` are already implemented but
**unused** in the balance path. We wire them in so a hydraulically unbalanced manifold is
handled from the first cycle, not only after the room-temp loop converges:

```
static_factor_i = normalize_i( demand_i × floor_factor_i × resistance_factor_i )

  demand_i          = area_i · heat_loss_i                 // design heat → flow need
  floor_factor_i    = floor_correction_factor_(floor_type_i, cover_mm_i)
                      //  high-R covering (carpet/wood) needs more flow to emit the same heat
  resistance_factor_i = length_term(L_i) · pipe_correction_factor_(pipe_type_i)
      L_i           = calculate_pipe_length_m_(area_i, spacing_i, supply_pipe_i)
      length_term   = L_i / L_ref     // longer loop ⇒ more opening for equal flow
```

`normalize_i(·)` divides by the manifold maximum so the result stays in `(0, 1]`. Each factor
is **multiplicatively neutral (1.0) when its input is unknown**, so the model degrades
gracefully to the demand-only prior and the adaptive loop absorbs the rest.

The exact exponents (how strongly length/diameter weigh) are tunable and don't need to be
exact — the static prior only has to get the *ordering* roughly right; `adapt_i` corrects
magnitude. Keep the existing `[0.85, 1.35]` clamp on `pipe_correction_factor_` and add a
matching clamp on `length_term` so one mis-entered number can't dominate.

### 1b. Inputs the user provides

The principle: **ask only for what a homeowner can realistically find, give everything else a
safe default, and let the adaptive loop cover the uncertainty.**

| Input | Status | If missing |
|---|---|---|
| **Area (m²)** | **Required** — everyone knows room size | n/a (already required) |
| **Pipe type** (e.g. PEX 16 mm) | **Required** — printed on the pipe / install docs | n/a |
| **Floor type** (tile / wood / carpet) | **Required** — visible | n/a |
| Pipe spacing (mm) | **Optional** — hard to know without plans | default **200 mm** (standard); `length_term` still computed from area |
| Heat loss (W/m²) | Optional | sensible default (or derive from `exterior_walls`) |
| Floor cover thickness | Optional | floor-type default |
| Supply-pipe run to manifold | Optional | existing default (`supply_pipe_length_m = 2.0`) |

So the *minimum* a user must enter for a meaningful prior is **area + pipe type + floor
type** — three things anyone can determine by looking. Spacing is the one genuinely hard
number, so it is optional with a **200 mm** default; getting it wrong only shifts the
`length_term`, which the adaptive loop then trims out. The dashboard should mark the three
required fields and visually de-emphasise the optional ones (with their defaults shown).

**Why 200 mm, not 150 mm.** Pipe length per m² = `area / spacing`, so the default directly
scales the modelled loop length and resistance:

| Spacing | Pipe per m² | 15 m² room | Use |
|---|---|---|-----|
| 300 mm  | 3.3 m/m² | ~50 m | low demand / well-insulated |
| **200 mm** | **5.0 m/m²** | **~75 m** | **standard living space (default)** |
| 150 mm  | 6.7 m/m² | ~100 m | high output (bathrooms, edge zones) |

150 mm is a *high-output* spacing — defaulting to it overestimates loop length by ~33 % vs
200 mm (and ~2× vs 300 mm), which both inflates the resistance term and pushes normal-size
rooms past the over-length warning threshold (≈100 m for 16 mm PEX). 200 mm is the
representative middle and matches the existing `ZoneConfig::pipe_spacing_mm = 200` default.
**Note:** the current `calculate_pipe_length_m_()` fallback for an empty spacing is `0.15 m`
([:1493](../components/hv6_zone_controller/hv6_zone_controller.cpp#L1493)) — inconsistent
with the 200 mm config default; change it to `0.20 m` as part of this work.
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

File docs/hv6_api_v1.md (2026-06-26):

# HV6 API v1 Contract

This document defines the dedicated dashboard API contract for HeatValve-6.

## Scope

- Dedicated namespace: `/api/hv6/v1`
- Dashboard transport: HTTP JSON + SSE
- Home Assistant integration remains on ESPHome API/entities/services
- Dashboard no longer depends on ESPHome entity-name REST routes
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

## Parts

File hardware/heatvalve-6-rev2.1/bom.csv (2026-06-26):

Refs | Value | Footprint | Qty | DNP | MPN | LCSC
C1 | 10u | Capacitor_SMD:C_0603_1608Metric | 1
C2,C8,C9,C11,C12,C19-C21,C30,C32,C34,C36,C38,C40,C50,C51,C53 | 100n | Capacitor_SMD:C_0603_1608Metric | 17
C3 | 100u | Capacitor_SMD:CP_Elec_6.3x7.7 | 1
C4 | 22n | Capacitor_SMD:C_0603_1608Metric | 1
C5,C6 | 22u | Capacitor_SMD:C_0805_2012Metric | 2
C7,C10 | 10u | Capacitor_SMD:C_0805_2012Metric | 2
C13,C52 | 4.7n | Capacitor_SMD:C_0603_1608Metric | 2
C14,C17,C18 | 1u | Capacitor_SMD:C_0603_1608Metric | 3
C54 | 100n DNP | Capacitor_SMD:C_0603_1608Metric | 1 | yes
C31,C33,C35,C37,C39,C41 | 1u | Capacitor_SMD:C_0805_2012Metric | 6
D1 | USB | LED_SMD:LED_0603_1608Metric | 1
D2 | PWR | LED_SMD:LED_0603_1608Metric | 1
D3 | FAULT | LED_SMD:LED_0603_1608Metric | 1
D4 | PERMIT | LED_SMD:LED_0603_1608Metric | 1
D5 | BAT54S ADC clamp | Package_TO_SOT_SMD:SOT-23 | 1
D6 | PESD3V3U1UL | Diode_SMD:D_SOD-323 | 1
D7 | BAT54S BEMF ADC clamp | Package_TO_SOT_SMD:SOT-23 | 1
F1 | 500mA PTC | Fuse:Fuse_1206_3216Metric | 1 |  | 1206L050
FB1 | 600R@100MHz | Inductor_SMD:L_0603_1608Metric_Pad1.05x0.95mm_HandSolder | 1
J1 | USB4105-GF-A | Connector_USB:USB_C_Receptacle_GCT_USB4105-xx-A_16P_TopMnt_Horizontal | 1 |  | USB4105-GF-A
J2 | MOTOR 1 4P4C | Connector_RJ:RJ9_Evercom_5301-440xxx_Horizontal | 1 |  | 5301-4P4C | C3097715
J3 | MOTOR 2 4P4C | Connector_RJ:RJ9_Evercom_5301-440xxx_Horizontal | 1 |  | 5301-4P4C | C3097715
J4 | MOTOR 3 4P4C | Connector_RJ:RJ9_Evercom_5301-440xxx_Horizontal | 1 |  | 5301-4P4C | C3097715
J5 | MOTOR 4 4P4C | Connector_RJ:RJ9_Evercom_5301-440xxx_Horizontal | 1 |  | 5301-4P4C | C3097715
J6 | MOTOR 5 4P4C | Connector_RJ:RJ9_Evercom_5301-440xxx_Horizontal | 1 |  | 5301-4P4C | C3097715
J7 | MOTOR 6 4P4C | Connector_RJ:RJ9_Evercom_5301-440xxx_Horizontal | 1 |  | 5301-4P4C | C3097715
J8 | ONEWIRE 1 | TerminalBlock_4Ucon:TerminalBlock_4Ucon_1x03_P3.50mm_Horizontal | 1
J9 | ONEWIRE 2 | TerminalBlock_4Ucon:TerminalBlock_4Ucon_1x03_P3.50mm_Horizontal | 1
J10 | ONEWIRE 3 | TerminalBlock_4Ucon:TerminalBlock_4Ucon_1x03_P3.50mm_Horizontal | 1
J11 | I2C EXPANSION DNP | Connector_PinHeader_2.54mm:PinHeader_1x04_P2.54mm_Vertical | 1 | yes
L1 | 4.7uH / >=2.4A | Inductor_SMD:L_Wuerth_HCI-5040 | 1
R1,R2 | 5.1k | Resistor_SMD:R_0603_1608Metric | 2
R3,R4 | 22R | Resistor_SMD:R_0603_1608Metric | 2
R5 | 115k | Resistor_SMD:R_0603_1608Metric | 1
R6 | 25.5k | Resistor_SMD:R_0603_1608Metric | 1
R7,R8,R15,R16,R23,R26,R28,R56,R59,R70-R81 | 10k | Resistor_SMD:R_0603_1608Metric | 21
R9-R12 | 2.2k | Resistor_SMD:R_0603_1608Metric | 4
R13 | 0R | Resistor_SMD:R_0603_1608Metric | 1
R14,R25,R54 | 1k | Resistor_SMD:R_0603_1608Metric | 3
R27,R55,R57,R60-R62 | 100k | Resistor_SMD:R_0603_1608Metric | 6
R50,R52 | 90.9k 1% | Resistor_SMD:R_0603_1608Metric | 2
R51,R53 | 47k 1% | Resistor_SMD:R_0603_1608Metric | 2
R58 | 1M | Resistor_SMD:R_0603_1608Metric | 1
R24 | 18k | Resistor_SMD:R_0603_1608Metric | 1
R29 | 47k | Resistor_SMD:R_0603_1608Metric | 1
R40 | 33R | Resistor_SMD:R_0603_1608Metric | 1
R41 | 4.7k | Resistor_SMD:R_0603_1608Metric | 1
R42,R43 | 2.2k DNP | Resistor_SMD:R_0603_1608Metric | 2 | yes
RSH1 | 1.0R 1% | Resistor_SMD:R_1206_3216Metric | 1 |  | 1.0R 1206 1%
RSH2 | DNP | Resistor_SMD:R_1206_3216Metric | 1 | yes
SW1 | RESET | Button_Switch_SMD:SW_SPST_PTS810 | 1
SW2 | BOOT | Button_Switch_SMD:SW_SPST_PTS810 | 1
U1 | ESP32-S3-WROOM-1-N16R8 | RF_Module:ESP32-S3-WROOM-1 | 1 |  | ESP32-S3-WROOM-1-N16R8 | C2913202
U2 | USBLC6-2SC6 | Package_TO_SOT_SMD:SOT-23-6 | 1
U3 | MT2492 | Package_TO_SOT_SMD:SOT-23-6 | 1 |  | MT2492 | C89358
U9 | INA180A1 (x20) | Package_TO_SOT_SMD:SOT-23-5 | 1 |  | INA180A1IDBVR
U10 | MCP6004 | Package_SO:SOIC-14_3.9x8.7mm_P1.27mm | 1 |  | MCP6004-I/SL
U11 | LM339B | Package_SO:SOIC-14_3.9x8.7mm_P1.27mm | 1 |  | LM339BDR
U12 | 74HC74 | Package_SO:SOIC-14_3.9x8.7mm_P1.27mm | 1
U13,U14 | 74HC4051 | Package_SO:TSSOP-16_4.4x5mm_P0.65mm | 2 |  | 74HC4051PW
U21-U26 | DRV8837DSGR | Package_SON:WSON-8-1EP_2x2mm_P0.5mm_EP0.9x1.6mm | 6 |  | DRV8837DSGR | C39159

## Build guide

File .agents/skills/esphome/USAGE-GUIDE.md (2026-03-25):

# ESPHome Code Assistant - Usage Guide

Complete guide with 50+ usage examples organized by skill level. Learn how to get the most out of this skill.

## Table of Contents

- [How It Works](#how-it-works)
- [Beginner Examples](#beginner-examples)
- [Intermediate Examples](#intermediate-examples)
- [Advanced Examples](#advanced-examples)
- [Troubleshooting Examples](#troubleshooting-examples)
- [Tips and Tricks](#tips-and-tricks)

---

## How It Works

### Basic Interaction Pattern

1. **Describe what you want** in natural language
2. **Claude generates** complete, working YAML configs
3. **Copy to ESPHome** dashboard and flash

### Example Conversation

**You:** Create an ESP32 with a DHT22 temperature and humidity sensor on GPIO4

**Claude:** Here's a complete ESPHome configuration:

```yaml
# Generated by supercharge-esphome-skill v1.0.0
# https://github.com/tonylofgren/supercharge-smart-home-claude-skills

esphome:
  name: temperature-sensor
  friendly_name: Temperature Sensor

esp32:
  board: esp32dev

wifi:
  ssid: !secret wifi_ssid
  password: !secret wifi_password

api:
  encryption:
    key: !secret api_key

ota:
  platform: esphome
  password: !secret ota_password

logger:

sensor:
  - platform: dht
    pin: GPIO4
    model: DHT22
    temperature:
      name: "Temperature"
    humidity:
      name: "Humidity"
    update_interval: 30s
```

---

## Beginner Examples

### 1. First Sensor Device

**You:** Create my first ESPHome device - an ESP32 that monitors room temperature

**What you get:**
- Complete working config
- WiFi setup with secrets
- Home Assistant API integration
- OTA updates enabled
- DHT or Dallas temperature sensor

---

### 2. Simple On/Off Switch

**You:** Add a relay switch on GPIO12 that I can control from Home Assistant

**What you get:**
```yaml
switch:
  - platform: gpio
    pin: GPIO12
    name: "Relay"
    id: relay_switch
    restore_mode: RESTORE_DEFAULT_OFF
```

---

### 3. Button Input

**You:** Add a physical button on GPIO5 that toggles the relay when pressed

**What you get:**
```yaml
binary_sensor:
  - platform: gpio
    pin:
      number: GPIO5
      mode: INPUT_PULLUP
      inverted: true
    name: "Button"
    on_press:
      - switch.toggle: relay_switch
```

---

### 4. Status LED

**You:** Add a status LED on GPIO2 that shows when the device is connected

**What you get:**
```yaml
status_led:
  pin: GPIO2

# Or for more control:
light:
  - platform: status_led
    name: "Status LED"
    pin: GPIO2
```

---

### 5. WiFi Signal Monitoring

**You:** Show me how to monitor WiFi signal strength

**What you get:**
```yaml
sensor:
  - platform: wifi_signal
    name: "WiFi Signal"
    update_interval: 60s
    entity_category: diagnostic
```

---

### 6. Device Uptime

**You:** Track how long the device has been running

**What you get:**
```yaml
sensor:
  - platform: uptime
    name: "Uptime"
    entity_category: diagnostic
```

---

### 7. Restart Button

**You:** Add a button in Home Assistant to restart the ESP device

**What you get:**
```yaml
button:
  - platform: restart
    name: "Restart"
    entity_category: config
```

---

### 8. Simple Light Control

**You:** Control an LED on GPIO13 with dimming

**What you get:**
```yaml
output:
  - platform: ledc
    pin: GPIO13
    id: led_output

light:
  - platform: monochromatic
    name: "LED"
    output: led_output
```

---

### 9. Door/Window Sensor

**You:** Create a door sensor using a reed switch on GPIO14

**What you get:**
```yaml
binary_sensor:
  - platform: gpio
    pin:
      number: GPIO14
      mode: INPUT_PULLUP
    name: "Door"
    device_class: door
    filters:
      - delayed_on: 100ms
      - delayed_off: 100ms
```

---

### 10. Motion Sensor (PIR)

**You:** Add a PIR motion sensor on GPIO27

**What you get:**
```yaml
binary_sensor:
  - platform: gpio
    pin: GPIO27
    name: "Motion"
    device_class: motion
    filters:
      - delayed_off: 30s  # Keep motion active for 30s after last trigger
```

---

## Intermediate Examples

### 11. Multiple Sensors Combo

**You:** Create a multi-sensor with temperature, humidity, pressure, and light level

**What you get:**
- BME280 for temp/humidity/pressure
- BH1750 for light level
- Proper I2C bus configuration
- All sensors with appropriate update intervals

---

### 12. RGB LED Strip

**You:** Add a WS2812 LED strip with 60 LEDs on GPIO25

**What you get:**
```yaml
light:
  - platform: esp32_rmt_led_strip
    pin: GPIO25
    num_leds: 60
    rmt_channel: 0
    chipset: WS2812
    rgb_order: GRB
    name: "LED Strip"
    effects:
      - rainbow:
      - pulse:
      - strobe:
      - color_wipe:
```

---

### 13. Energy Monitoring

**You:** Add power monitoring using a CT clamp and SCT-013-030

**What you get:**
```yaml
sensor:
  - platform: ct_clamp
    sensor: adc_sensor
    name: "Power"
    sample_duration: 200ms
    update_interval: 5s
    filters:
      - calibrate_linear:
          - 0 -> 0
          - 0.02 -> 30  # 30A CT at 30A = 1V, ADC reads 0.02
    unit_of_measurement: "A"

  - platform: adc
    pin: GPIO34
    id: adc_sensor
    attenuation: 11db
```

---

### 14. OLED Display

**You:** Add an SSD1306 OLED display showing temperature and time

**What you get:**
```yaml
i2c:
  sda: GPIO21
  scl: GPIO22

display:
  - platform: ssd1306_i2c
    model: "SSD1306 128x64"
    address: 0x3C
    lambda: |-
      it.printf(0, 0, id(font1), "Temp: %.1f°C", id(temperature).state);
      it.strftime(0, 20, id(font1), "%H:%M", id(sntp_time).now());

font:
  - file: "gfonts://Roboto"
    id: font1
    size: 16

time:
  - platform: sntp
    id: sntp_time
```

---

### 15. Thermostat Control

**You:** Create a thermostat that controls a heater relay based on temperature

**What you get:**
```yaml
climate:
  - platform: thermostat
    name: "Thermostat"
    sensor: temperature_sensor
    default_preset: Home
    preset:
      - name: Home
        default_target_temperature_low: 20°C
      - name: Away
        default_target_temperature_low: 16°C
    heat_action:
      - switch.turn_on: heater_relay
    idle_action:
      - switch.turn_off: heater_relay
    heat_deadband: 0.5°C
    heat_overrun: 0.5°C
```

---

### 16. Garage Door Controller

**You:** Create a garage door controller with position sensing and safety features

**What you get:**
- Cover component with open/close/stop
- Reed switches for open/closed detection
- Obstruction sensor input
- Relay control with timing
- Safety lockout when obstructed

---

### 17. IR Remote Hub

**You:** Create an IR transmitter to control my Samsung TV

**What you get:**
```yaml
remote_transmitter:
  pin: GPIO4
  carrier_duty_percent: 50%

button:
  - platform: template
    name: "TV Power"
    on_press:
      - remote_transmitter.transmit_samsung:
          data: 0xE0E040BF  # Samsung power code

  - platform: template
    name: "TV Volume Up"
    on_press:
      - remote_transmitter.transmit_samsung:
          data: 0xE0E0E01F
```

---

### 18. Pulse Counter (Water Meter)

**You:** Monitor water usage with a pulse meter

**What you get:**
```yaml
sensor:
  - platform: pulse_meter
    pin: GPIO5
    name: "Water Flow"
    unit_of_measurement: "L/min"
    filters:
      - multiply: 0.5  # Adjust for your meter's pulses per liter
    total:
      name: "Total Water"
      unit_of_measurement: "L"
      accuracy_decimals: 0
```

---

### 19. Shelly 1PM Conversion

**You:** Convert my Shelly 1PM to ESPHome

**What you get:**
- Correct GPIO mappings for Shelly 1PM
- HLW8012 power monitoring
- Button input
- Relay output
- Temperature monitoring
- LED status

---

### 20. Sonoff Basic Conversion

**You:** Flash my Sonoff Basic with ESPHome

**What you get:**
- ESP8266 configuration
- Correct GPIO for relay (GPIO12)
- Button on GPIO0
- LED on GPIO13
- Safe mode recovery

---

### 21. Stepper Motor Control

**You:** Control a stepper motor for blinds

**What you get:**
```yaml
stepper:
  - platform: a4988
    id: blind_stepper
    step_pin: GPIO16
    dir_pin: GPIO17
    max_speed: 500 steps/s
    acceleration: 200 steps/s^2

cover:
  - platform: template
    name: "Blinds"
    open_action:
      - stepper.set_target:
          id: blind_stepper
          target: 2000
    close_action:
      - stepper.set_target:
          id: blind_stepper
          target: 0
```

---

### 22. PWM Fan Control

**You:** Create a PWM fan controller with speed levels

**What you get:**
```yaml
output:
  - platform: ledc
    pin: GPIO25
    id: fan_output
    frequency: 25000Hz

fan:
  - platform: speed
    output: fan_output
    name: "Fan"
    speed_count: 10
```

---

### 23. Capacitive Touch Buttons

**You:** Add touch buttons using ESP32 touch pins

**What you get:**
```yaml
esp32_touch:
  setup_mode: false

binary_sensor:
  - platform: esp32_touch
    name: "Touch Button 1"
    pin: GPIO4
    threshold: 1000
    on_press:
      - light.toggle: led

  - platform: esp32_touch
    name: "Touch Button 2"
    pin: GPIO15
    threshold: 1000
```

---

### 24. Time-Based Automation

**You:** Turn on lights at sunset and off at 11 PM

**What you get:**
```yaml
sun:
  latitude: 59.3293°
  longitude: 18.0686°

time:
  - platform: sntp
    id: sntp_time
    on_time:
      - seconds: 0
        minutes: 0
        hours: 23
        then:
          - light.turn_off: outdoor_light

    on_time_sync:
      then:
        - logger.log: "Time synchronized"

interval:
  - interval: 1min
    then:
      - if:
          condition:
            sun.is_below_horizon:
          then:
            - light.turn_on: outdoor_light
```

---

### 25. MQTT Integration

**You:** Use MQTT instead of Home Assistant API

**What you get:**
```yaml
mqtt:
  broker: 192.168.1.100
  username: !secret mqtt_user
  password: !secret mqtt_password
  discovery: true
  topic_prefix: esphome/device_name

sensor:
  - platform: dht
    pin: GPIO4
    temperature:
      name: "Temperature"
      state_topic: esphome/device_name/temperature/state
    humidity:
      name: "Humidity"
```

---

## Advanced Examples

### 26. Victron MPPT Monitoring

**You:** Monitor my Victron SmartSolar MPPT via VE.Direct

**What you get:**
- External component configuration
- UART setup for VE.Direct
- All available sensors (PV voltage, power, battery, yield)
- Charging state text sensor

---

### 27. JK-BMS Battery Monitoring

**You:** Monitor my JK-BMS via Bluetooth

**What you get:**
```yaml
external_components:
  - source: github://syssi/esphome-jk-bms@main
    components: [jk_bms_ble]

esp32_ble_tracker:

jk_bms_ble:
  - id: jk_bms
    mac_address: "C8:47:8C:XX:XX:XX"

sensor:
  - platform: jk_bms_ble
    jk_bms_ble_id: jk_bms
    total_voltage:
      name: "Battery Voltage"
    current:
      name: "Battery Current"
    power:
      name: "Battery Power"
    state_of_charge:
      name: "State of Charge"
    cell_voltage_1:
      name: "Cell 1"
    # ... all cells
```

---

### 28. Voice Assistant

**You:** Create a voice assistant with wake word detection

**What you get:**
- ESP32-S3 with PSRAM configuration
- I2S microphone setup
- Speaker output
- Wake word engine
- Home Assistant voice pipeline integration

---

### 29. BLE Presence Detection

**You:** Create a Bluetooth presence detector for room occupancy

**What you get:**
```yaml
esp32_ble_tracker:
  scan_parameters:
    interval: 1100ms
    window: 1100ms
    active: true

binary_sensor:
  - platform: ble_presence
    mac_address: "XX:XX:XX:XX:XX:XX"
    name: "Phone Present"
    device_class: presence

  - platform: ble_presence
    ibeacon_uuid: "xxxxxxxx-xxxx-xxxx-xxxx-xxxxxxxxxxxx"
    name: "iBeacon Present"
```

---

### 30. Deep Sleep for Battery

**You:** Optimize my sensor for battery operation with deep sleep

**What you get:**
```yaml
deep_sleep:
  run_duration: 30s
  sleep_duration: 5min
  wakeup_pin: GPIO33
  wakeup_pin_mode: INVERT_WAKEUP

sensor:
  - platform: adc
    pin: GPIO34
    name: "Battery Voltage"
    attenuation: 11db
    filters:
      - multiply: 2  # Voltage divider factor
    on_value_range:
      - below: 3.3
        then:
          - deep_sleep.prevent: deep_sleep_1
          - logger.log: "Battery low, preventing sleep for charging"
```

---

### 31. PID Climate Control

**You:** Create a thermostat with PID control for precise temperature

**What you get:**
```yaml
climate:
  - platform: pid
    name: "PID Thermostat"
    sensor: temperature_sensor
    default_target_temperature: 21°C
    heat_output: heater_output
    control_parameters:
      kp: 0.5
      ki: 0.01
      kd: 0.1
      output_averaging_samples: 5
      derivative_averaging_samples: 5
```

---

### 32. E-Paper Display Dashboard

**You:** Create a low-power e-paper dashboard for weather and sensors

**What you get:**
- Waveshare e-paper configuration
- Deep sleep between updates
- Home Assistant data fetching
- Multi-page layout
- Battery monitoring

---

### 33. CAN Bus Integration

**You:** Read data from a vehicle CAN bus

**What you get:**
```yaml
canbus:
  - platform: esp32_can
    tx_pin: GPIO21
    rx_pin: GPIO22
    can_id: 0x100
    bit_rate: 500kbps

sensor:
  - platform: template
    name: "Vehicle Speed"
    id: vehicle_speed
    unit_of_measurement: "km/h"

interval:
  - interval: 100ms
    then:
      - canbus.send:
          can_id: 0x7DF
          data: [0x02, 0x01, 0x0D, 0x00, 0x00, 0x00, 0x00, 0x00]
```

---

### 34. Modbus RTU Sensors

**You:** Read a Modbus energy meter

**What you get:**
```yaml
uart:
  tx_pin: GPIO17
  rx_pin: GPIO16
  baud_rate: 9600
  stop_bits: 1

modbus:
  id: modbus_hub

modbus_controller:
  - id: energy_meter
    address: 0x01
    modbus_id: modbus_hub
    update_interval: 5s

sensor:
  - platform: modbus_controller
    modbus_controller_id: energy_meter
    name: "Voltage"
    register_type: holding
    address: 0x0000
    unit_of_measurement: "V"
    value_type: U_WORD
    accuracy_decimals: 1
    filters:
      - multiply: 0.1
```

---

### 35. Custom Lambda Sensors

**You:** Create a sensor that calculates power from voltage and current

**What you get:**
```yaml
sensor:
  - platform: template
    name: "Calculated Power"
    lambda: |-
      float voltage = id(voltage_sensor).state;
      float current = id(current_sensor).state;
      if (isnan(voltage) || isnan(current)) {
        return NAN;
      }
      return voltage * current;
    unit_of_measurement: "W"
    update_interval: 5s
```

---

### 36. Home Assistant Services

**You:** Create custom services I can call from Home Assistant

**What you get:**
```yaml
api:
  services:
    - service: set_led_color
      variables:
        red: int
        green: int
        blue: int
      then:
        - light.turn_on:
            id: rgb_led
            red: !lambda "return red / 255.0;"
            green: !lambda "return green / 255.0;"
            blue: !lambda "return blue / 255.0;"

    - service: play_rtttl
      variables:
        song: string
      then:
        - rtttl.play: !lambda "return song;"
```

---

### 37. NFC Tag Reader

**You:** Add NFC tag reading for access control

**What you get:**
```yaml
pn532_spi:
  cs_pin: GPIO5
  update_interval: 1s

binary_sensor:
  - platform: pn532
    uid: XX-XX-XX-XX
    name: "NFC Tag 1"
    on_press:
      - switch.turn_on: door_lock
      - delay: 5s
      - switch.turn_off: door_lock

text_sensor:
  - platform: pn532
    name: "NFC Tag UID"
```

---

### 38. Nextion Display

**You:** Integrate a Nextion touch display

**What you get:**
```yaml
uart:
  tx_pin: GPIO17
  rx_pin: GPIO16
  baud_rate: 9600

display:
  - platform: nextion
    id: nextion_display
    update_interval: 5s
    lambda: |-
      it.set_component_text("temp", to_string(id(temperature).state).c_str());
      it.set_component_value("gauge", (int)(id(humidity).state));
```

---

### 39. Air Quality Monitor

**You:** Build an AirGradient-style air quality monitor

**What you get:**
- PM2.5 sensor (PMS5003)
- CO2 sensor (SenseAir S8)
- Temperature/humidity (SHT40)
- OLED display
- All sensors properly configured

---

### 40. Washing Machine Monitor

**You:** Monitor my washing machine using a vibration sensor

**What you get:**
```yaml
sensor:
  - platform: adc
    pin: GPIO34
    name: "Vibration"
    id: vibration
    update_interval: 1s

binary_sensor:
  - platform: template
    name: "Washing Machine Running"
    lambda: |-
      return id(vibration).state > 0.5;
    filters:
      - delayed_on: 30s
      - delayed_off: 2min
    on_release:
      - homeassistant.event:
          event: esphome.washing_done
```

---

## Troubleshooting Examples

### 41. WiFi Connection Issues

**You:** My ESPHome device won't connect to WiFi

**What you get:**
- Diagnostic checklist
- Signal strength testing config
- Fallback AP configuration
- Static IP configuration
- Hidden network setup

---

### 42. Sensor Returns NaN

**You:** My DHT22 sensor shows NaN instead of values

**What you get:**
- Wiring verification steps
- Pull-up resistor configuration
- Longer update intervals
- Debug logging setup

---

### 43. OTA Update Fails

**You:** OTA updates keep failing

**What you get:**
- Memory usage diagnostic config
- Timeout adjustment
- Large update workarounds
- USB fallback instructions

---

### 44. Boot Loop

**You:** My ESP32 keeps restarting

**What you get:**
- Power supply checks
- Strapping pin warnings
- Safe mode config
- Memory leak detection

---

### 45. Debug Lambda Errors

**You:** My lambda code has an error but I don't know where

**What you get:**
```yaml
logger:
  level: VERBOSE
  logs:
    component: DEBUG
    sensor: DEBUG

# Add logging to your lambda
sensor:
  - platform: template
    lambda: |-
      ESP_LOGD("custom", "Voltage: %f", id(voltage).state);
      ESP_LOGD("custom", "Current: %f", id(current).state);
      float result = id(voltage).state * id(current).state;
      ESP_LOGD("custom", "Result: %f", result);
      return result;
```

---

### 46. Compile Errors

**You:** ESPHome won't compile, shows "undefined reference"

**What you get:**
- Common library conflicts
- Platform version fixes
- Component compatibility checks

---

### 47. Slow Response

**You:** My device is slow to respond to Home Assistant

**What you get:**
- Update interval optimization
- Network diagnostics
- API buffer settings

---

### 48. Flash Memory Full

**You:** I get "out of program storage space" error

**What you get:**
- Board variant check
- Component trimming guide
- External logging options

---

### 49. Sensor Noise/Spikes

**You:** My sensor readings are very noisy

**What you get:**
```yaml
sensor:
  - platform: adc
    pin: GPIO34
    filters:
      - sliding_window_moving_average:
          window_size: 10
          send_every: 5
      - median:
          window_size: 5
      - delta: 0.1  # Only send if changed by 0.1
```

---

### 50. I2C Device Not Found

**You:** ESPHome can't find my I2C sensor

**What you get:**
- I2C scan config
- Address verification
- Pull-up configuration
- Speed adjustment

---

## Tips and Tricks

### Effective Communication

| Instead of... | Say... |
|---|---|
| "I need help with ESPHome" | "Create an ESP32 config for a DHT22 on GPIO4" |
| "Fix my config" | "Fix this error: [paste actual error]" |
| "Make it work with Home Assistant" | "Add a custom service to control brightness from HA" |
| "It doesn't work" | "Sensor shows NaN - here's my config: [paste YAML]" |

### Iterative Building

1. Start simple: Get basic config working first
2. Add one component at a time
3. Test after each addition
4. Ask for troubleshooting if something breaks

### Using Templates

Say: "Show me the base-esp32.yaml template" to get a starting point, then customize.

### Getting Pin Recommendations

Say: "What GPIO should I use for [component] on ESP32?" for board-specific advice.

### External Components

Say: "Is there an external component for [device]?" to find community solutions.

---

## Reference

For detailed component documentation, see:

- [sensors.md](references/sensors.md) - 200+ sensor platforms
- [binary-sensors.md](references/binary-sensors.md) - PIR, touch, NFC
- [lights.md](references/lights.md) - LED strips, effects
- [displays.md](references/displays.md) - OLED, TFT, E-Paper
- [climate.md](references/climate.md) - Thermostat, PID
- [automations.md](references/automations.md) - Triggers, actions
- [troubleshooting.md](references/troubleshooting.md) - Common issues

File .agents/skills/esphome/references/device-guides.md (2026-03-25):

# ESPHome Device Conversion Guides

## Table of Contents
- [Shelly Devices](#shelly-devices)
- [Sonoff Devices](#sonoff-devices)
- [Tuya Devices](#tuya-devices)
- [Xiaomi/Aqara BLE](#xiaomiaqara-ble)
- [Generic ESP Modules](#generic-esp-modules)

---

## Shelly Devices

### Shelly 1 (ESP8266)

```yaml
substitutions:
  device_name: "shelly-1"
  friendly_name: "Shelly 1"

esphome:
  name: ${device_name}
  friendly_name: ${friendly_name}

esp8266:
  board: esp01_1m

wifi:
  ssid: !secret wifi_ssid
  password: !secret wifi_password
  ap:
    ssid: "${device_name}-fallback"

captive_portal:
api:
ota:
  platform: esphome
logger:

binary_sensor:
  - platform: gpio
    pin:
      number: GPIO5
      mode: INPUT_PULLUP
    name: "Switch"
    on_press:
      - switch.toggle: relay

switch:
  - platform: gpio
    id: relay
    name: "Relay"
    pin: GPIO4
    restore_mode: RESTORE_DEFAULT_OFF
```

### Shelly 1PM (ESP8266 with Power Monitoring)

```yaml
substitutions:
  device_name: "shelly-1pm"
  friendly_name: "Shelly 1PM"

esphome:
  name: ${device_name}
  friendly_name: ${friendly_name}

esp8266:
  board: esp01_1m

wifi:
  ssid: !secret wifi_ssid
  password: !secret wifi_password
  ap:

captive_portal:
api:
ota:
  platform: esphome
logger:
  baud_rate: 0  # Disable UART logging (uses TX for power monitoring)

binary_sensor:
  - platform: gpio
    pin:
      number: GPIO4
      mode: INPUT_PULLUP
    name: "Switch"
    on_press:
      - switch.toggle: relay

switch:
  - platform: gpio
    id: relay
    name: "Relay"
    pin: GPIO15
    restore_mode: RESTORE_DEFAULT_OFF

sensor:
  - platform: hlw8012
    sel_pin: GPIO12
    cf_pin: GPIO5
    cf1_pin: GPIO14
    current:
      name: "Current"
    voltage:
      name: "Voltage"
    power:
      name: "Power"
    energy:
      name: "Energy"
    current_resistor: 0.001 ohm
    voltage_divider: 1925
    change_mode_every: 1
    update_interval: 5s

status_led:
  pin:
    number: GPIO0
    inverted: true
```

### Shelly 2.5 (Dual Relay with Power)

```yaml
substitutions:
  device_name: "shelly-25"

esphome:
  name: ${device_name}

esp8266:
  board: esp01_1m

# ... wifi, api, ota, logger ...

i2c:
  sda: GPIO12
  scl: GPIO14

sensor:
  - platform: ade7953_i2c
    irq_pin: GPIO16
    voltage:
      name: "Voltage"
    current_a:
      name: "Current 1"
    current_b:
      name: "Current 2"
    power_a:
      name: "Power 1"
    power_b:
      name: "Power 2"
    energy_a:
      name: "Energy 1"
    energy_b:
      name: "Energy 2"
    update_interval: 5s

  - platform: ntc
    sensor: temp_resistance
    name: "Temperature"
    calibration:
      b_constant: 3350
      reference_resistance: 10kOhm
      reference_temperature: 25C

  - platform: resistance
    id: temp_resistance
    sensor: temp_analog
    configuration: DOWNSTREAM
    resistor: 32kOhm

  - platform: adc
    id: temp_analog
    pin: A0
    update_interval: 10s

switch:
  - platform: gpio
    id: relay1
    name: "Relay 1"
    pin: GPIO4
  - platform: gpio
    id: relay2
    name: "Relay 2"
    pin: GPIO5

binary_sensor:
  - platform: gpio
    pin: GPIO13
    name: "Switch 1"
    on_press:
      - switch.toggle: relay1
  - platform: gpio
    pin: GPIO5
    name: "Switch 2"
    on_press:
      - switch.toggle: relay2
```

### Shelly Plus 1PM (ESP32-based)

```yaml
substitutions:
  device_name: "shelly-plus-1pm"

esphome:
  name: ${device_name}

esp32:
  board: esp32doit-devkit-v1
  framework:
    type: esp-idf

wifi:
  ssid: !secret wifi_ssid
  password: !secret wifi_password

api:
ota:
  platform: esphome
logger:

binary_sensor:
  - platform: gpio
    pin:
      number: GPIO4
      mode: INPUT_PULLUP
    name: "Switch"
    on_press:
      - switch.toggle: relay

switch:
  - platform: gpio
    id: relay
    name: "Relay"
    pin: GPIO26
    restore_mode: RESTORE_DEFAULT_OFF

sensor:
  - platform: bl0937
    cf_pin: GPIO7
    cf1_pin: GPIO8
    sel_pin:
      number: GPIO6
      inverted: true
    current:
      name: "Current"
    voltage:
      name: "Voltage"
    power:
      name: "Power"
    energy:
      name: "Energy"
    update_interval: 5s

  - platform: ntc
    sensor: temp_resistance
    name: "Temperature"
    calibration:
      b_constant: 3350
      reference_resistance: 10kOhm
      reference_temperature: 25C

  - platform: resistance
    id: temp_resistance
    sensor: temp_analog
    configuration: DOWNSTREAM
    resistor: 10kOhm

  - platform: adc
    id: temp_analog
    pin: GPIO35
    attenuation: 11db

status_led:
  pin:
    number: GPIO0
    inverted: true
```

### Shelly Dimmer 2

```yaml
substitutions:
  device_name: "shelly-dimmer"

esphome:
  name: ${device_name}

esp8266:
  board: esp01_1m

uart:
  tx_pin: GPIO1
  rx_pin: GPIO3
  baud_rate: 115200

light:
  - platform: shelly_dimmer
    name: "Dimmer"
    firmware:
      version: "51.6"
    power:
      name: "Power"
    voltage:
      name: "Voltage"
    current:
      name: "Current"
    min_brightness: 100
    max_brightness: 1000
    warmup_brightness: 20

binary_sensor:
  - platform: gpio
    pin: GPIO14
    name: "Switch 1"
  - platform: gpio
    pin: GPIO12
    name: "Switch 2"
```

### Shelly Uni (Universal Input)

```yaml
substitutions:
  device_name: "shelly-uni"

esphome:
  name: ${device_name}

esp8266:
  board: esp01_1m

binary_sensor:
  - platform: gpio
    pin:
      number: GPIO12
      mode: INPUT_PULLUP
    name: "Input 1"
  - platform: gpio
    pin:
      number: GPIO13
      mode: INPUT_PULLUP
    name: "Input 2"

switch:
  - platform: gpio
    id: relay1
    name: "Relay 1"
    pin: GPIO15
  - platform: gpio
    id: relay2
    name: "Relay 2"
    pin: GPIO4

sensor:
  - platform: adc
    pin: A0
    name: "ADC"
    update_interval: 10s
    filters:
      - multiply: 30.3  # Voltage divider for 30V max

  # DS18B20 temperature sensors (optional)
one_wire:
  - platform: gpio
    pin: GPIO5

sensor:
  - platform: dallas_temp
    address: 0xXXXXXXXXXXXXXXXX
    name: "Temperature"
```

---

## Sonoff Devices

### Sonoff Basic R2 (ESP8266)

```yaml
substitutions:
  device_name: "sonoff-basic"
  friendly_name: "Sonoff Basic"

esphome:
  name: ${device_name}
  friendly_name: ${friendly_name}

esp8266:
  board: esp8285

wifi:
  ssid: !secret wifi_ssid
  password: !secret wifi_password
  ap:

captive_portal:
api:
ota:
  platform: esphome
logger:

binary_sensor:
  - platform: gpio
    pin:
      number: GPIO0
      mode: INPUT_PULLUP
      inverted: true
    name: "Button"
    on_press:
      - switch.toggle: relay

switch:
  - platform: gpio
    id: relay
    name: "Relay"
    pin: GPIO12
    restore_mode: RESTORE_DEFAULT_OFF

status_led:
  pin:
    number: GPIO13
    inverted: true
```

### Sonoff Mini R2

```yaml
substitutions:
  device_name: "sonoff-mini"

esphome:
  name: ${device_name}

esp8266:
  board: esp8285

binary_sensor:
  - platform: gpio
    pin:
      number: GPIO0
      mode: INPUT_PULLUP
      inverted: true
    name: "Button"
    on_press:
      - switch.toggle: relay

  - platform: gpio
    pin:
      number: GPIO4
      mode: INPUT_PULLUP
    name: "Switch"
    on_state:
      - switch.toggle: relay

switch:
  - platform: gpio
    id: relay
    name: "Relay"
    pin: GPIO12
    restore_mode: RESTORE_DEFAULT_OFF

status_led:
  pin:
    number: GPIO13
    inverted: true
```

### Sonoff 4CH Pro R3

```yaml
substitutions:
  device_name: "sonoff-4ch"

esphome:
  name: ${device_name}

esp8266:
  board: esp8285

binary_sensor:
  - platform: gpio
    pin:
      number: GPIO0
      mode: INPUT_PULLUP
      inverted: true
    name: "Button 1"
    on_press:
      - switch.toggle: relay1

  - platform: gpio
    pin:
      number: GPIO9
      mode: INPUT_PULLUP
      inverted: true
    name: "Button 2"
    on_press:
      - switch.toggle: relay2

  - platform: gpio
    pin:
      number: GPIO10
      mode: INPUT_PULLUP
      inverted: true
    name: "Button 3"
    on_press:
      - switch.toggle: relay3

  - platform: gpio
    pin:
      number: GPIO14
      mode: INPUT_PULLUP
      inverted: true
    name: "Button 4"
    on_press:
      - switch.toggle: relay4

switch:
  - platform: gpio
    id: relay1
    name: "Relay 1"
    pin: GPIO12
  - platform: gpio
    id: relay2
    name: "Relay 2"
    pin: GPIO5
  - platform: gpio
    id: relay3
    name: "Relay 3"
    pin: GPIO4
  - platform: gpio
    id: relay4
    name: "Relay 4"
    pin: GPIO15

status_led:
  pin:
    number: GPIO13
    inverted: true
```

### Sonoff POW R2 (Power Monitoring)

```yaml
substitutions:
  device_name: "sonoff-pow"

esphome:
  name: ${device_name}

esp8266:
  board: esp8285

logger:
  baud_rate: 0  # Disable UART logging

uart:
  rx_pin: GPIO3
  baud_rate: 4800

sensor:
  - platform: cse7766
    current:
      name: "Current"
    voltage:
      name: "Voltage"
    power:
      name: "Power"
    energy:
      name: "Energy"
    update_interval: 5s

binary_sensor:
  - platform: gpio
    pin:
      number: GPIO0
      mode: INPUT_PULLUP
      inverted: true
    name: "Button"
    on_press:
      - switch.toggle: relay

switch:
  - platform: gpio
    id: relay
    name: "Relay"
    pin: GPIO12
    restore_mode: RESTORE_DEFAULT_OFF

status_led:
  pin:
    number: GPIO13
    inverted: true
```

### Sonoff TH16 (Temperature/Humidity)

```yaml
substitutions:
  device_name: "sonoff-th16"

esphome:
  name: ${device_name}

esp8266:
  board: esp8285

sensor:
  - platform: dht
    pin: GPIO14
    model: SI7021  # or DHT11, AM2301
    temperature:
      name: "Temperature"
    humidity:
      name: "Humidity"
    update_interval: 30s

binary_sensor:
  - platform: gpio
    pin:
      number: GPIO0
      mode: INPUT_PULLUP
      inverted: true
    name: "Button"
    on_press:
      - switch.toggle: relay

switch:
  - platform: gpio
    id: relay
    name: "Relay"
    pin: GPIO12
    restore_mode: RESTORE_DEFAULT_OFF

status_led:
  pin:
    number: GPIO13
    inverted: true
```

### Sonoff S31 (US Plug with Power)

```yaml
substitutions:
  device_name: "sonoff-s31"

esphome:
  name: ${device_name}

esp8266:
  board: esp8285

logger:
  baud_rate: 0

uart:
  rx_pin: GPIO3
  baud_rate: 4800

sensor:
  - platform: cse7766
    current:
      name: "Current"
    voltage:
      name: "Voltage"
    power:
      name: "Power"
    energy:
      name: "Energy"

binary_sensor:
  - platform: gpio
    pin:
      number: GPIO0
      mode: INPUT_PULLUP
      inverted: true
    name: "Button"
    on_press:
      - switch.toggle: relay

switch:
  - platform: gpio
    id: relay
    name: "Relay"
    pin: GPIO12

status_led:
  pin:
    number: GPIO13
    inverted: true
```

---

## Tuya Devices

### Tuya MCU Devices

Many Tuya devices use a separate MCU for control. ESPHome communicates via UART.

```yaml
uart:
  rx_pin: GPIO3
  tx_pin: GPIO1
  baud_rate: 9600

tuya:

switch:
  - platform: tuya
    name: "Switch"
    switch_datapoint: 1

sensor:
  - platform: tuya
    name: "Temperature"
    sensor_datapoint: 2
    unit_of_measurement: "C"
    accuracy_decimals: 1
    filters:
      - multiply: 0.1

number:
  - platform: tuya
    name: "Target Temperature"
    number_datapoint: 3
    min_value: 15
    max_value: 35
    step: 1
```

### Common Tuya Datapoints

| Datapoint | Common Use |
|---|---|
| 1 | Power/Switch on/off |
| 2 | Temperature (x0.1) |
| 3 | Target temperature |
| 4 | Mode/Speed |
| 5 | Child lock |
| 101+ | Custom functions |

### Tuya Dimmer

```yaml
uart:
  rx_pin: GPIO3
  tx_pin: GPIO1
  baud_rate: 9600

tuya:

light:
  - platform: tuya
    name: "Dimmer"
    switch_datapoint: 1
    dimmer_datapoint: 2
    min_value: 10
    max_value: 1000
```

### Tuya RGB Light

```yaml
uart:
  rx_pin: GPIO3
  tx_pin: GPIO1
  baud_rate: 9600

tuya:

light:
  - platform: tuya
    name: "RGB Light"
    switch_datapoint: 20
    dimmer_datapoint: 22
    color_datapoint: 24
    color_type: rgbhsv  # or hsv
```

### Flashing Tuya Devices

**Methods:**
1. **tuya-convert** - OTA flash (may not work on newer devices)
2. **CloudCutter** - OTA for newer Beken chips
3. **Serial flash** - Direct connection to ESP chip

**tuya-convert (older devices):**
```bash
git clone https://github.com/ct-Open-Source/tuya-convert
cd tuya-convert
./install_prereq.sh
./start_flash.sh
```

**CloudCutter (Beken chips):**
```bash
# See https://github.com/tuya-cloudcutter/tuya-cloudcutter
```

---

## Xiaomi/Aqara BLE

### Enable BLE Tracker

```yaml
esp32_ble_tracker:
  scan_parameters:
    interval: 1100ms
    window: 1100ms
    active: true
```

### Xiaomi LYWSD03MMC (Temperature/Humidity)

```yaml
sensor:
  - platform: xiaomi_lywsd03mmc
    mac_address: "A4:C1:38:XX:XX:XX"
    bindkey: "xxxxxxxxxxxxxxxxxxxxxxxxxxxxxxxx"
    temperature:
      name: "Temperature"
    humidity:
      name: "Humidity"
    battery_level:
      name: "Battery"
```

### Getting Bindkey

1. Use **TelinkFlasher** to extract bindkey:
   - https://pvvx.github.io/ATC_MiThermometer/TelinkMiFlasher.html
2. Or flash **ATC firmware** (no bindkey needed):
   - Changes protocol to ATC format

### ATC Firmware (Custom)

```yaml
sensor:
  - platform: atc_mithermometer
    mac_address: "A4:C1:38:XX:XX:XX"
    temperature:
      name: "Temperature"
    humidity:
      name: "Humidity"
    battery_level:
      name: "Battery"
    battery_voltage:
      name: "Battery Voltage"
```

### Xiaomi MJYD2S Motion Sensor

```yaml
binary_sensor:
  - platform: xiaomi_mjyd2s
    mac_address: "XX:XX:XX:XX:XX:XX"
    bindkey: "xxxxxxxxxxxxxxxxxxxxxxxxxxxxxxxx"
    name: "Motion"
    idle_time:
      name: "Idle Time"
    battery_level:
      name: "Battery"
    light:
      name: "Light"
```

### Xiaomi Door/Window Sensor

```yaml
binary_sensor:
  - platform: xiaomi_mccgq02hl
    mac_address: "XX:XX:XX:XX:XX:XX"
    bindkey: "xxxxxxxxxxxxxxxxxxxxxxxxxxxxxxxx"
    name: "Door"
    battery_level:
      name: "Battery"
```

### Scanning for BLE Devices

```yaml
# Add to your config temporarily
esp32_ble_tracker:
  on_ble_advertise:
    then:
      - lambda: |-
          ESP_LOGD("ble", "MAC: %s, RSSI: %d",
            x.address_str().c_str(), x.get_rssi());
```

---

## Generic ESP Modules

### ESP-01 (1MB Flash)

```yaml
esphome:
  name: esp01-device

esp8266:
  board: esp01_1m

# Limited GPIO: GPIO0, GPIO2 (with restrictions)
# GPIO0: Must be HIGH during boot
# GPIO2: Must be HIGH during boot (often used for LED)

binary_sensor:
  - platform: gpio
    pin:
      number: GPIO0
      mode: INPUT_PULLUP
    name: "Button"

status_led:
  pin:
    number: GPIO2
    inverted: true
```

### ESP-12F / NodeMCU

```yaml
esphome:
  name: nodemcu-device

esp8266:
  board: nodemcuv2

# Available GPIO: 0, 2, 4, 5, 12, 13, 14, 15, 16
# GPIO15: Must be LOW during boot
# GPIO0, 2: Must be HIGH during boot
```

### ESP32 DevKit

```yaml
esphome:
  name: esp32-device

esp32:
  board: esp32dev

# ADC1 (usable with WiFi): GPIO32-39
# ADC2 (not usable with WiFi): GPIO0, 2, 4, 12-15, 25-27
# Touch: GPIO0, 2, 4, 12-15, 27, 32, 33
# Strapping pins: GPIO0, 2, 5, 12, 15
```

### ESP32-S3

```yaml
esphome:
  name: esp32s3-device

esp32:
  board: esp32-s3-devkitc-1
  framework:
    type: esp-idf  # Recommended for S3

# USB: GPIO19 (D-), GPIO20 (D+)
# PSRAM: GPIO33-37 (if applicable)
```

### ESP32-C3

```yaml
esphome:
  name: esp32c3-device

esp32:
  board: esp32-c3-devkitm-1
  framework:
    type: esp-idf

# Limited GPIO: 0-10, 18-21
# USB: GPIO18 (D-), GPIO19 (D+)
```

---

## Flashing Methods

### Web Flasher (Easiest)

1. Go to https://web.esphome.io
2. Connect device via USB
3. Flash firmware directly from browser

### ESPHome Dashboard

```bash
# Install ESPHome
pip install esphome

# Compile and flash
esphome run device.yaml

# First flash (serial)
esphome run device.yaml --device /dev/ttyUSB0

# OTA flash
esphome run device.yaml
```

### Serial Flashing Wiring

| ESP Pin | USB-Serial |
|---|---|
| 3V3 | 3.3V |
| GND | GND |
| TX | RX |
| RX | TX |
| GPIO0 | GND (during flash) |

**Boot mode:** Hold GPIO0 LOW, power cycle, then release.

### OTA Updates

```yaml
ota:
  platform: esphome
  password: !secret ota_password

# For HTTP OTA (larger updates)
ota:
  - platform: esphome
  - platform: http_request
```

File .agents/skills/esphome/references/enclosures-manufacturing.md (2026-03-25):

# Enclosures, PCB Design & Manufacturing Guide

From prototype to production — enclosures, PCB design with KiCad, certification, and manufacturing.

## Table of Contents

1. [Enclosure Design](#enclosure-design)
2. [IP Ratings](#ip-ratings)
3. [PCB Design with KiCad](#pcb-design-with-kicad)
4. [PCB Manufacturing](#pcb-manufacturing)
5. [Certification (CE/FCC/RoHS)](#certification-cefccrohs)
6. [Manufacturing at Scale](#manufacturing-at-scale)
7. [Quality Control](#quality-control)

## Enclosure Design

### Methods by Volume

| Volume | Method | Cost/unit | Tooling | Lead Time | Quality |
|---|---|---|---|---|---|
| 1-20 | FDM 3D print | $2-10 | $0 | 1-4 hours | Functional |
| 20-100 | SLA/MJF 3D print | $5-15 | $0 | 1-2 days | Good finish |
| 100-500 | 3D print farm (JLCPCB, Craftcloud) | $3-8 | $0 | 5-10 days | Consistent |
| 500-2000 | Silicone mold + resin cast | $2-5 | $200-500 | 2-4 weeks | Good |
| 2000+ | Injection molding | $0.30-2 | $2000-8000 | 4-8 weeks | Professional |

### 3D Printing for Prototypes and Small Batches

**FDM Materials:**

| Material | Strength | Heat Resist | UV Resist | Ease | Best For |
|---|---|---|---|---|---|
| PLA | Medium | 60°C | Poor | Easy | Indoor prototypes |
| PETG | Good | 80°C | Good | Medium | Indoor products |
| ASA | Good | 100°C | Excellent | Medium | Outdoor enclosures |
| ABS | Good | 100°C | Fair | Hard | Functional parts |
| Nylon (PA) | Excellent | 110°C | Good | Hard | Mechanical stress |

**Recommendation:** PETG for indoor products, ASA for outdoor.

**Design Rules for 3D Printed Enclosures:**
- Wall thickness: minimum 1.5mm (FDM), 1mm (SLA)
- Snap-fit tabs: 0.3mm interference, 45° lead-in angle
- Screw bosses: 6mm OD for M3 heat-set inserts ($0.05 each)
- PCB mounting: M2.5 standoffs, 3mm clearance under PCB
- Ventilation: Slot arrays (not round holes) for strength
- Text/logos: Emboss 0.5mm or deboss 0.3mm
- Tolerances: ±0.2mm (FDM), ±0.1mm (SLA)

### Off-the-Shelf Enclosures

For faster time-to-market, consider pre-made enclosures:

| Enclosure | Size (mm) | IP Rating | Price | Source |
|---|---|---|---|---|
| Hammond 1551-series | 35x35x20 to 80x80x40 | IP54 | $2-5 | Mouser |
| Bud Industries | Various | IP65 | $3-8 | Mouser |
| Gainta G-series | Various | IP65 | $2-6 | TME |
| Sonoff IP66 box | 100x68x50 | IP66 | $3 | AliExpress |
| DIN rail module | Various | — | $1-3 | AliExpress |

## IP Ratings

| Rating | Protection | Use Case |
|---|---|---|
| IP20 | Touch protection only | Indoor, dry |
| IP44 | Splash-proof | Bathroom, covered outdoor |
| IP54 | Dust-protected, splash | General outdoor |
| IP65 | Dust-tight, water jet | Outdoor, rain |
| IP67 | Dust-tight, immersion 1m | Underground, flooding risk |
| IP68 | Dust-tight, continuous submersion | Pool, irrigation |

### Achieving IP Ratings

| Rating | Method | Additional Cost |
|---|---|---|
| IP44 | Tight-fitting lid, cable glands | $0.50 |
| IP54 | Foam gasket in lid groove | $0.30 |
| IP65 | Silicone gasket, M12 cable glands | $1.00 |
| IP67 | O-ring seal, potted cable entries | $2.00 |
| IP68 | Epoxy potting entire PCB | $3.00 |

**Cable glands:** PG7 (3-6.5mm cable) $0.10, PG9 (4-8mm) $0.10, PG11 (5-10mm) $0.12

## PCB Design with KiCad

### KiCad Workflow

```
Schematic (Eeschema) → Footprint assignment → PCB layout (Pcbnew) → Gerber export → Order
```

### Schematic Checklist for ESP32 Products

1. **MCU module** (use module, not bare chip — saves layout complexity)
   - Decoupling: 100nF + 10µF on each VCC
   - EN pin: 10kΩ pullup + 100nF to GND (RC delay for power-on reset)
   - Boot pin (GPIO0): 10kΩ pullup (pulled low only for flashing)
   - UART: TX/RX accessible for debugging

2. **Power supply**
   - Input protection: Schottky diode or P-MOSFET reverse polarity
   - Regulator: Input and output capacitors per datasheet
   - LED: Power indicator (green, 1kΩ resistor for 3.3V)

3. **Sensors** (per sensor datasheet)
   - I2C: Check if pullups needed (many breakouts include them)
   - Decoupling: 100nF close to sensor VCC
   - Bypass: 10µF if sensor has high transient current

4. **Actuators**
   - Relay: Flyback diode (1N4148) across coil
   - MOSFET: Gate resistor (100Ω) + pulldown (10kΩ)
   - Motor: Decoupling + TVS protection

5. **Connectors**
   - USB-C: ESD protection (USBLC6-2)
   - External GPIO: TVS diodes
   - Programming: JST-SH or Tag-Connect pads

### PCB Layout Rules

**Antenna clearance (critical!):**
```
┌──────────────────────────────┐
│          ESP32 Module         │
│  ┌─────┐                     │
│  │ MCU │    ▓▓▓▓▓▓▓▓▓ ←── Antenna
│  └─────┘    ▓▓▓▓▓▓▓▓▓       │
│             ▓▓▓▓▓▓▓▓▓       │
├─────────────┼───────────────┤
│ Components  │  NO copper    │ ← Keep this area clear
│ OK here     │  NO traces    │   (both layers!)
│             │  NO GND plane │
└─────────────┴───────────────┘
```

**General rules:**
- 2-layer PCB is sufficient for most ESPHome products
- Trace width: 0.25mm (signal), 0.5mm+ (power), 1mm+ (high current)
- Via size: 0.3mm drill, 0.6mm pad (standard)
- Ground plane on bottom layer, pour on both layers
- Keep I2C/SPI traces under 10cm
- Route UART away from high-speed signals
- Test points: 1mm pads for multimeter probes

### KiCad Libraries for ESP32

| Library | Contents | Source |
|---|---|---|
| espressif-kicad | Official ESP32 symbols + footprints | GitHub: espressif/kicad-libraries |
| JLCPCB parts | Footprints matching JLCPCB's SMT library | easyeda2kicad converter |
| SnapEDA | Individual component models | snapeda.com |
| Ultra Librarian | Component models with 3D | ultralibrarian.com |

### EasyEDA as Alternative

If KiCad feels complex, EasyEDA (free, web-based) integrates directly with JLCPCB:
- LCSC component library built in
- One-click PCB ordering with SMT assembly
- Export to KiCad format if needed later

## PCB Manufacturing

### PCB-Only (you solder)

| Service | Min. 5 boards | Layers | Lead Time | Notes |
|---|---|---|---|---|
| JLCPCB | $2 + $3 ship | 1-6 | 3-7 days | Cheapest, reliable |
| PCBWay | $5 + $5 ship | 1-6 | 3-7 days | Good quality, flex PCBs |
| OSH Park | $5/sq inch | 2-4 | 12 days | US-made, purple |
| Aisler | €6 + ship | 2-4 | 5-10 days | EU-based, fast EU ship |
| ALLPCB | $0 (promo) | 2 | 5-7 days | Regular free promos |

### PCB + SMT Assembly (they solder SMD components)

| Service | Setup Cost | Per-board | Min Qty | Lead Time |
|---|---|---|---|---|
| JLCPCB SMT | $8 stencil | $0.004/joint | 5 | 5-10 days |
| PCBWay SMT | $10 stencil | $0.005/joint | 5 | 5-10 days |
| MacroFab | $0 | $10+ per board | 1 | 10-15 days |
| Elecrow | $10 | $0.004/joint | 10 | 7-14 days |

**Tip:** JLCPCB's "Economic PCBA" option is cheapest for small runs. Use their "Basic Parts" (common resistors, caps, ICs) for lowest cost — "Extended Parts" have a $3/unique part fee.

### Design for Assembly (DFA)

- Use one side only for SMD (reduces cost)
- Prefer 0402 or 0603 resistors/caps (standard for JLCPCB)
- Use JLCPCB basic parts where possible
- Add fiducial marks (3 on board) for pick-and-place alignment
- Panel boards if < 50x50mm for easier handling

## Certification (CE/FCC/RoHS)

### When Do You Need Certification?

| Scenario | CE (EU) | FCC (US) | Notes |
|---|---|---|---|
| Personal use | No | No | |
| Gift/prototype | No | No | |
| Selling in EU | Yes | — | Required for commercial sale |
| Selling in US | — | Yes | Required for commercial sale |
| Selling in both | Yes | Yes | |
| Selling on Amazon/Etsy | Yes or Yes | Yes or Yes | Marketplace policies require it |

### Using Pre-Certified Modules

**This is the most important cost-saving tip:** ESP32 modules (WROOM, MINI, S3-WROOM) are already FCC/CE certified by Espressif. If you use the module without modifying the antenna or RF circuitry, you can reference their certification — this dramatically reduces your testing costs.

**Requirements for "modular" certification approach:**
- Use the exact certified module (not bare chip)
- Do not modify antenna or RF circuit
- Follow module datasheet for antenna clearance
- Include the module's FCC ID in your product label
- Still need EMC/safety testing for the rest of your circuit

### Certification Costs

| Test | Typical Cost | Lead Time | Notes |
|---|---|---|---|
| EMC pre-scan | $500-1000 | 1 day | Find issues before formal test |
| CE EMC (EN 55032/35) | $2000-4000 | 2-3 weeks | Required for EU |
| CE Safety (LVD, if mains) | $1500-3000 | 2-3 weeks | Only for mains-powered |
| CE RED (radio) | $1500-3000 | 2-3 weeks | Usually covered by module cert |
| FCC Part 15 | $2000-5000 | 2-4 weeks | Can reference module FCC ID |
| RoHS declaration | $200-500 | Self-declaration possible | Based on component datasheets |
| **Total (typical)** | **$3000-8000** | **4-8 weeks** | |

### Reducing Certification Cost

1. **Use pre-certified WiFi/BLE module** (biggest savings — avoids RF testing)
2. **Low-voltage DC only** (avoid mains → skip LVD safety testing)
3. **EMC pre-scan first** ($500) — fix issues before paying for formal test
4. **Test one product, certify variants** — similar products can share test reports
5. **Self-declare RoHS** — based on component datasheets, no lab needed

### Documentation Required

- Technical file with schematics, PCB layout, BOM
- Risk assessment (basic for low-voltage products)
- Test reports from accredited lab (ILAC/ISO 17025)
- Declaration of Conformity (CE) — template available online
- User manual with safety information
- Product label with CE mark, FCC ID (module), model number

## Manufacturing at Scale

### Production Flow

```
Component sourcing → PCB + SMT assembly → Through-hole hand-solder
  → Firmware flashing → Functional test → Enclosure assembly
  → Final test → Packaging → Ship
```

### Firmware Flashing at Scale

**For 10-100 units:** USB-UART adapter + esptool.py script

```bash
# Flash one unit via serial
esptool.py --port /dev/ttyUSB0 write_flash 0x0 firmware.bin
```

**For 100+ units:** Test jig with pogo pins
- Design PCB pads for pogo pin contact (Tag-Connect TC2030 footprint)
- 3D print jig to align board
- Script auto-detects device, flashes, runs basic test
- Total flash + test time: ~30 seconds per unit

### Test Jig Design

```
┌─────────────────────┐
│   3D-printed cradle  │
│  ┌─────────────────┐ │
│  │  Pogo pins:     │ │
│  │  • 3V3 power    │ │
│  │  • GND          │ │
│  │  • TX (flash)   │ │
│  │  • RX (flash)   │ │
│  │  • GPIO0 (boot) │ │
│  │  • EN (reset)   │ │
│  └─────────────────┘ │
│  [Start Button]      │
└─────────────────────┘
```

### Automated Test Script

```python
#!/usr/bin/env python3
"""Production test script for ESPHome devices."""
import subprocess
import serial
import time

def test_device(port="/dev/ttyUSB0"):
    """Flash and test one unit."""
    # 1. Flash firmware
    subprocess.run([
        "esptool.py", "--port", port,
        "write_flash", "0x0", "firmware.bin"
    ], check=True)

    # 2. Wait for boot
    time.sleep(5)

    # 3. Check serial output for "WiFi connected"
    ser = serial.Serial(port, 115200, timeout=10)
    output = ser.read(2000).decode()
    assert "WiFi connected" in output, "WiFi failed"

    # 4. Check sensor readings
    assert "temperature:" in output, "Temp sensor not responding"

    print("PASS")
```

## Quality Control

### Incoming Inspection

- Check component reels against BOM (part numbers, values)
- Spot-check 5% of components with multimeter
- Verify PCB quality: solder mask, silkscreen, drill alignment

### In-Process QC

| Check | Method | Criteria |
|---|---|---|
| Solder joints | Visual + magnifier | No cold joints, bridges, or voids |
| Power supply | Multimeter | 3.3V ±5% under load |
| Current draw | USB meter | Within expected range |
| WiFi | Scan from 5m away | RSSI > -70 dBm |
| Sensors | Compare to reference | Within datasheet tolerance |
| OTA update | Push test firmware | Completes in < 60 seconds |

### Final Test

Run automated test script on every unit:
1. Power on → LED lights
2. WiFi connects (< 15 seconds)
3. Sensors report valid data
4. OTA update succeeds
5. API connection from HA works

### Defect Rate Targets

| Volume | Acceptable defect rate |
|---|---|
| < 50 units | < 5% (manual QC) |
| 50-500 | < 2% |
| 500+ | < 1% (automated testing) |

---

For component recommendations, see `hardware-selection.md`.
For the full development lifecycle, see `product-development.md`.

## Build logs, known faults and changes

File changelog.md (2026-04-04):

# Changelog

## v2.0.0 — ESP-IDF Rewrite (2025-07-09)

Complete rewrite from ESPHome YAML to pure ESP-IDF C++ with PlatformIO.

### Breaking Changes
- All ESPHome YAML configuration removed — firmware is now native C++
- Build system changed from ESPHome to PlatformIO (`make build` / `make flash`)
- Configuration via NVS + web dashboard instead of YAML substitutions

### Hardware (v2 PCB)
- Switched from legacy H-bridge + MUX to **6× DRV8215 I2C motor drivers**
- Removed INA219 + LMV358 tacho stage — current sensing via shared IPROPI (GPIO1)
- Added shared nSLEEP (GPIO2) and wired-OR nFAULT (GPIO7)
- Motor addresses: 0x30–0x35 via A1/A0 pin strapping

### Firmware
- **Pure ESP-IDF v5.x** with FreeRTOS tasks (no Arduino, no ESPHome runtime)
- 8 modular libraries: config_store, wifi_manager, valve_controller, sensor_manager, zone_controller, mqtt_handler, web_dashboard, ota_updater
- System manager with task watchdog (5s heartbeat) and coordinated startup
- Dual-core task layout: valve control on Core 1 (10ms), zone/sensor/mqtt on Core 0

### Control
- 4 algorithms retained: Tanh, Linear, PID, Adaptive (runtime-switchable)
- Hydraulic balancing with pipe length, spacing, and floor cover correction
- Failsafe: temperature timeout (5min → maintenance position), MQTT timeout (30min → clear offsets)
- Minimum flow enforcement (10% valve opening)

### Connectivity
- MQTT with Home Assistant auto-discovery (climate + sensor entities)
- Compatible with helios-6 Go service for multi-controller optimization
- Built-in web dashboard (responsive SPA, no external dependencies)
- OTA via HTTP POST to `/api/ota` with dual-partition rollback

### Documentation
- Rewrote ARCHITECTURE.md for ESP-IDF task model and data flow
- Rewrote README.md with PlatformIO build instructions and REST API reference

---

## v1.0.1 — Power & Docs Update (2026-02-13)

### Hardware
- ESP32 powered via 5V pin (VBUS) through SS14 Schottky diode for backfeed protection
- AMS1117 (3V3_LOG) now powers analog/peripherals only, not ESP32
- Added D_5V (SS14, 1A/40V, SMA) to BOM

### Documentation
- Updated power architecture: three independent paths (ESP32, 3V3_MOT, 3V3_LOG)
- Updated README GPIO table to match current design

---

## v1.0.0 — Initial Release (2026-02-13)

Complete redesign of HeatValve-6 floor heating valve controller.

### Hardware
- ESP32-S3 Super Mini with legacy H-bridge motor driver stage
- 6 valve channels via GAQY212GSX optocoupler multiplexing (odd/even)
- MUX inverter: SN74LVC1G04DBVR (U10)
- INA219 high-side current sense (I2C, 0x40, 100mΩ shunt on MCOM)
- LMV358 dual op-amp tacho conditioning (non-inverting amplifier + Schmitt trigger)
- Tuning pads (R12_ALT, R_REF2_ALT) for prototype tacho calibration
- MT2492 3.3V step-down (3V3_MOT), AMS1117-3.3V LDO (3V3_LOG)
- USB-C power input with 220µF bulk capacitor
- Dallas 1-Wire temperature sensors (8 probes)
- WS2812 status LED with color-coded states
- RJ11/RJ10 connectors, HmIP-VDMOT compatible (pin 1 + pin 3)

### GPIO Assignment
| GPIO | Function |
|---|---|
| GPIO2 | Motor MUX |
| GPIO3 | ENA1 (DRV #2 nSLEEP) |
| GPIO4 | ENA2 (DRV #3 nSLEEP) |
| GPIO5 | DIR2 (IN2) |
| GPIO6 | DIR1 (IN1) |
| GPIO7 | Tacho (LMV358 output) |
| GPIO8 | I2C SCL |
| GPIO9 | I2C SDA |
| GPIO10 | 1-Wire |
| GPIO11 | ENA0 (DRV #1 nSLEEP) |
| GPIO48 | WS2812 LED |
| GPIO1, 12, 13 | Spare |

### Software
- ESPHome-based firmware with modular YAML architecture
- 4 control profiles: Tanh, Linear, PID, Remote
- Current-based endstop detection with adaptive mean learning
- IIR low-pass filtered current measurement (INA219)
- Tacho revolution counting via LMV358 Schmitt trigger
- Hydraulic balancing mode
- Standalone operation with WS2812 status indication

### Documentation
- Full schematic documentation (analog, motor, controller, power)
- Net naming convention: M1+..M6+, MNODD, MNEVEN, MCOM
- CC BY-NC-SA 4.0 license

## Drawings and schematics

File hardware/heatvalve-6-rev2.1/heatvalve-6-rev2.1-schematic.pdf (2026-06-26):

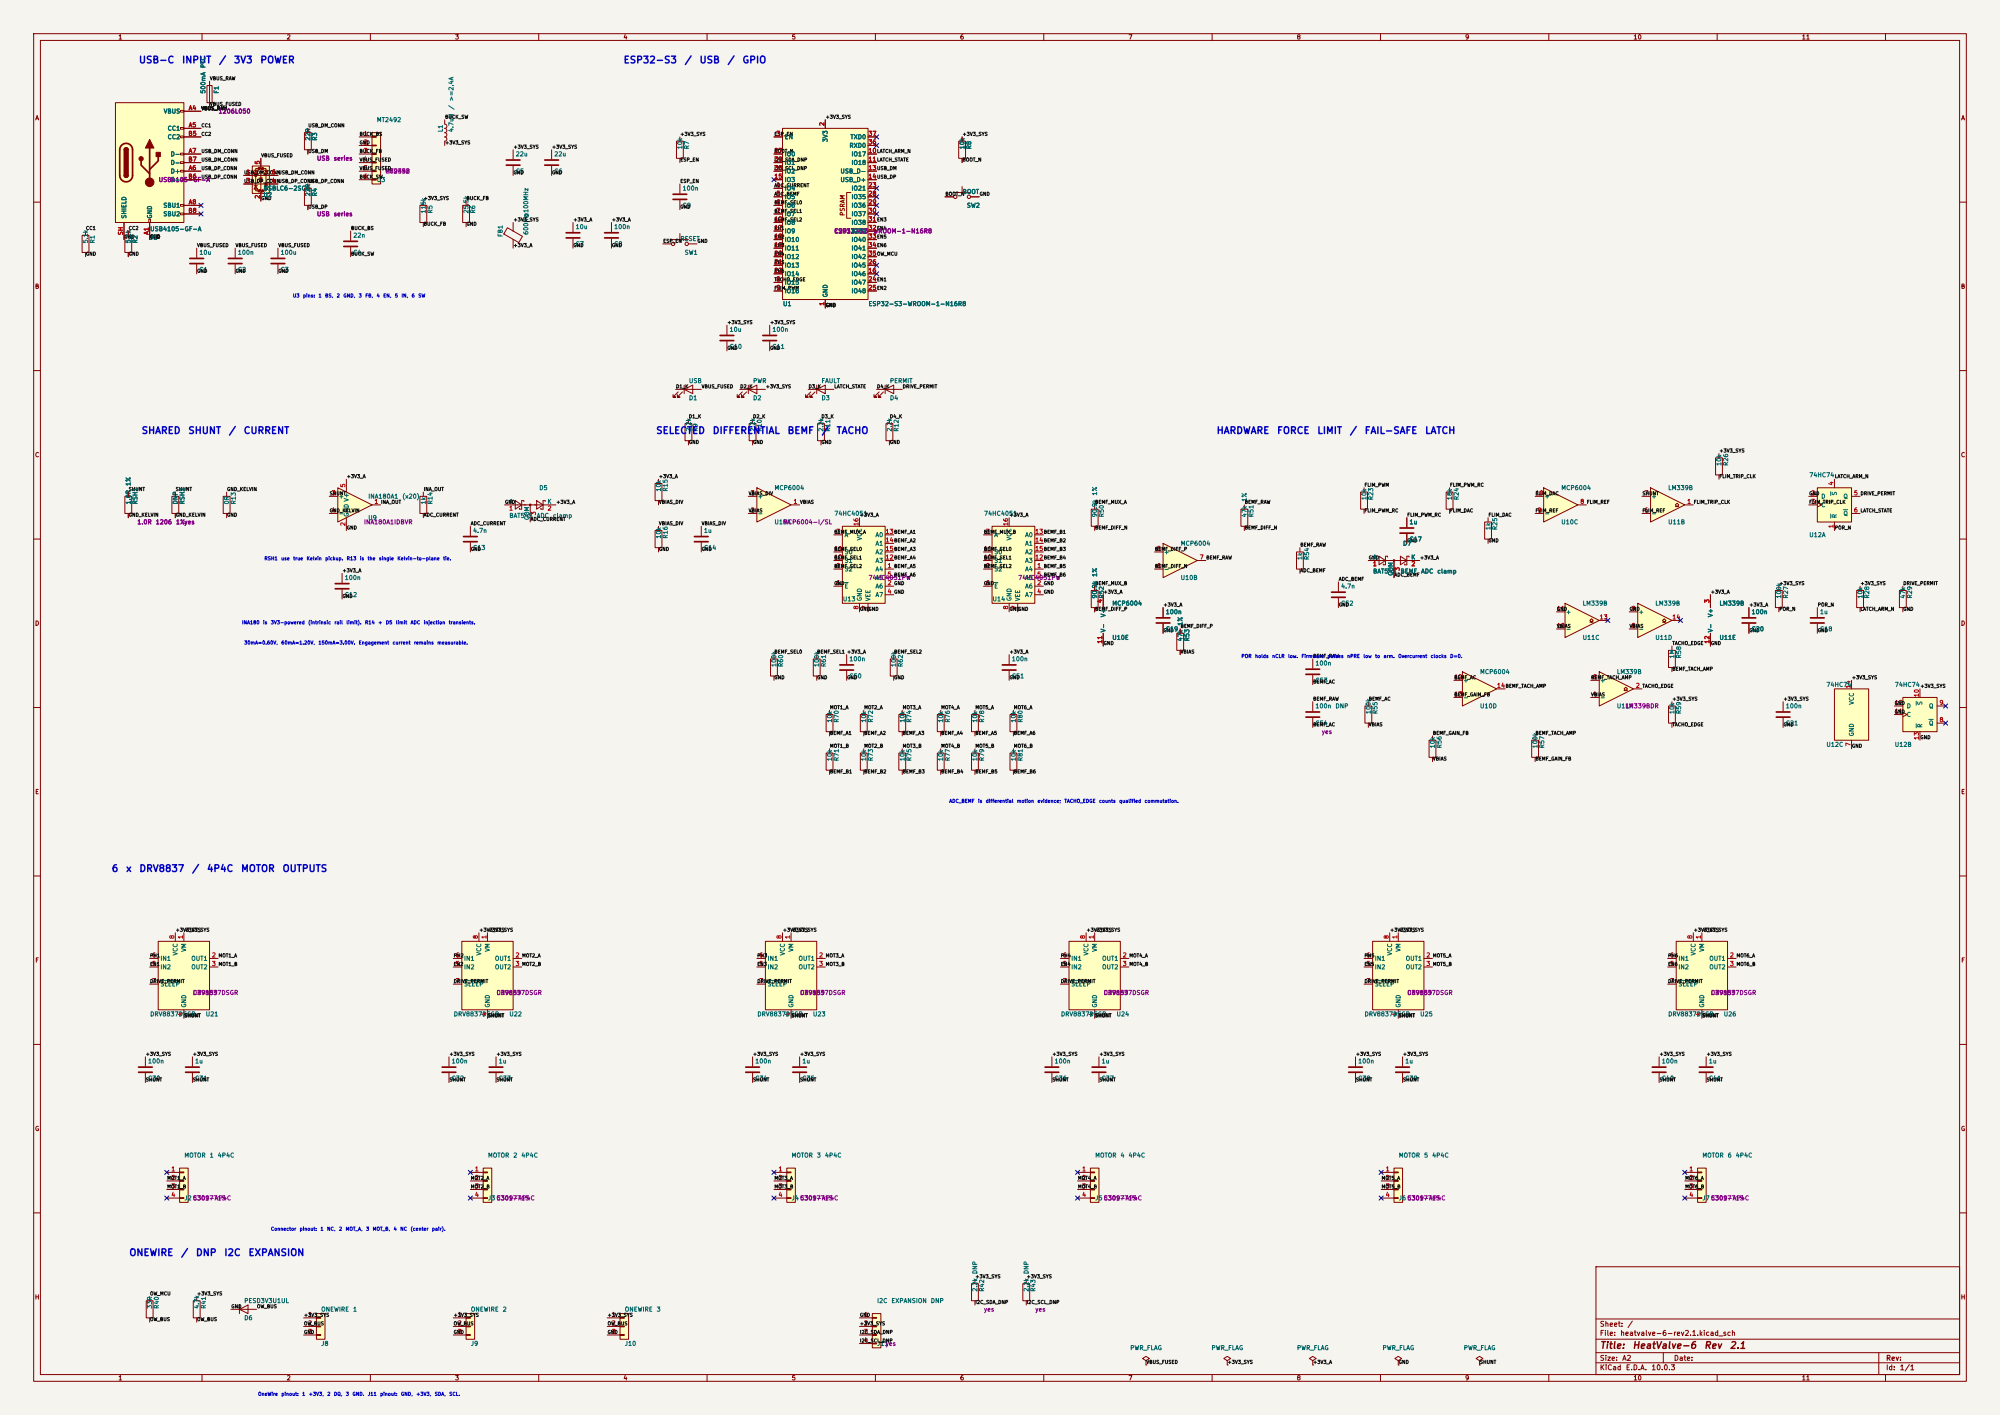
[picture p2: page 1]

USB-C INPUT / 3V3 POWER
INA180 is 3V3-powered (intrinsic rail limit). R14 + D5 limit ADC injection transients. 30mA=0.60V, 60mA=1.20V, 150mA=3.00V. Engagement current remains measurable. RSH1 use true Kelvin pickup. R13 is the single Kelvin-to-plane tie. 22R R3 USB series 22R R4 USB series U2USBLC6-2SC6

U3 pins: 1 BS, 2 GND, 3 FB, 4 EN, 5 IN, 6 SW
C3097715 5301-4P4C 1.0R RSH1 1%

POR holds nCLR low. Firmware pulses nPRE low to arm. Overcurrent clocks D=0. SHARED SHUNT / CURRENT
INA180A1IDBVR 0RR13 C31

Connector pinout: 1 NC, 2 MOT_A, 3 MOT_B, 4 NC (center pair).

Size: A2 | Rev:
KiCad E.D.A. 10.0.3 | Id: 1/1

OneWire pinout: 1 +3V3, 2 DQ, 3 GND. J11 pinout: GND, +3V3, SDA, SCL.

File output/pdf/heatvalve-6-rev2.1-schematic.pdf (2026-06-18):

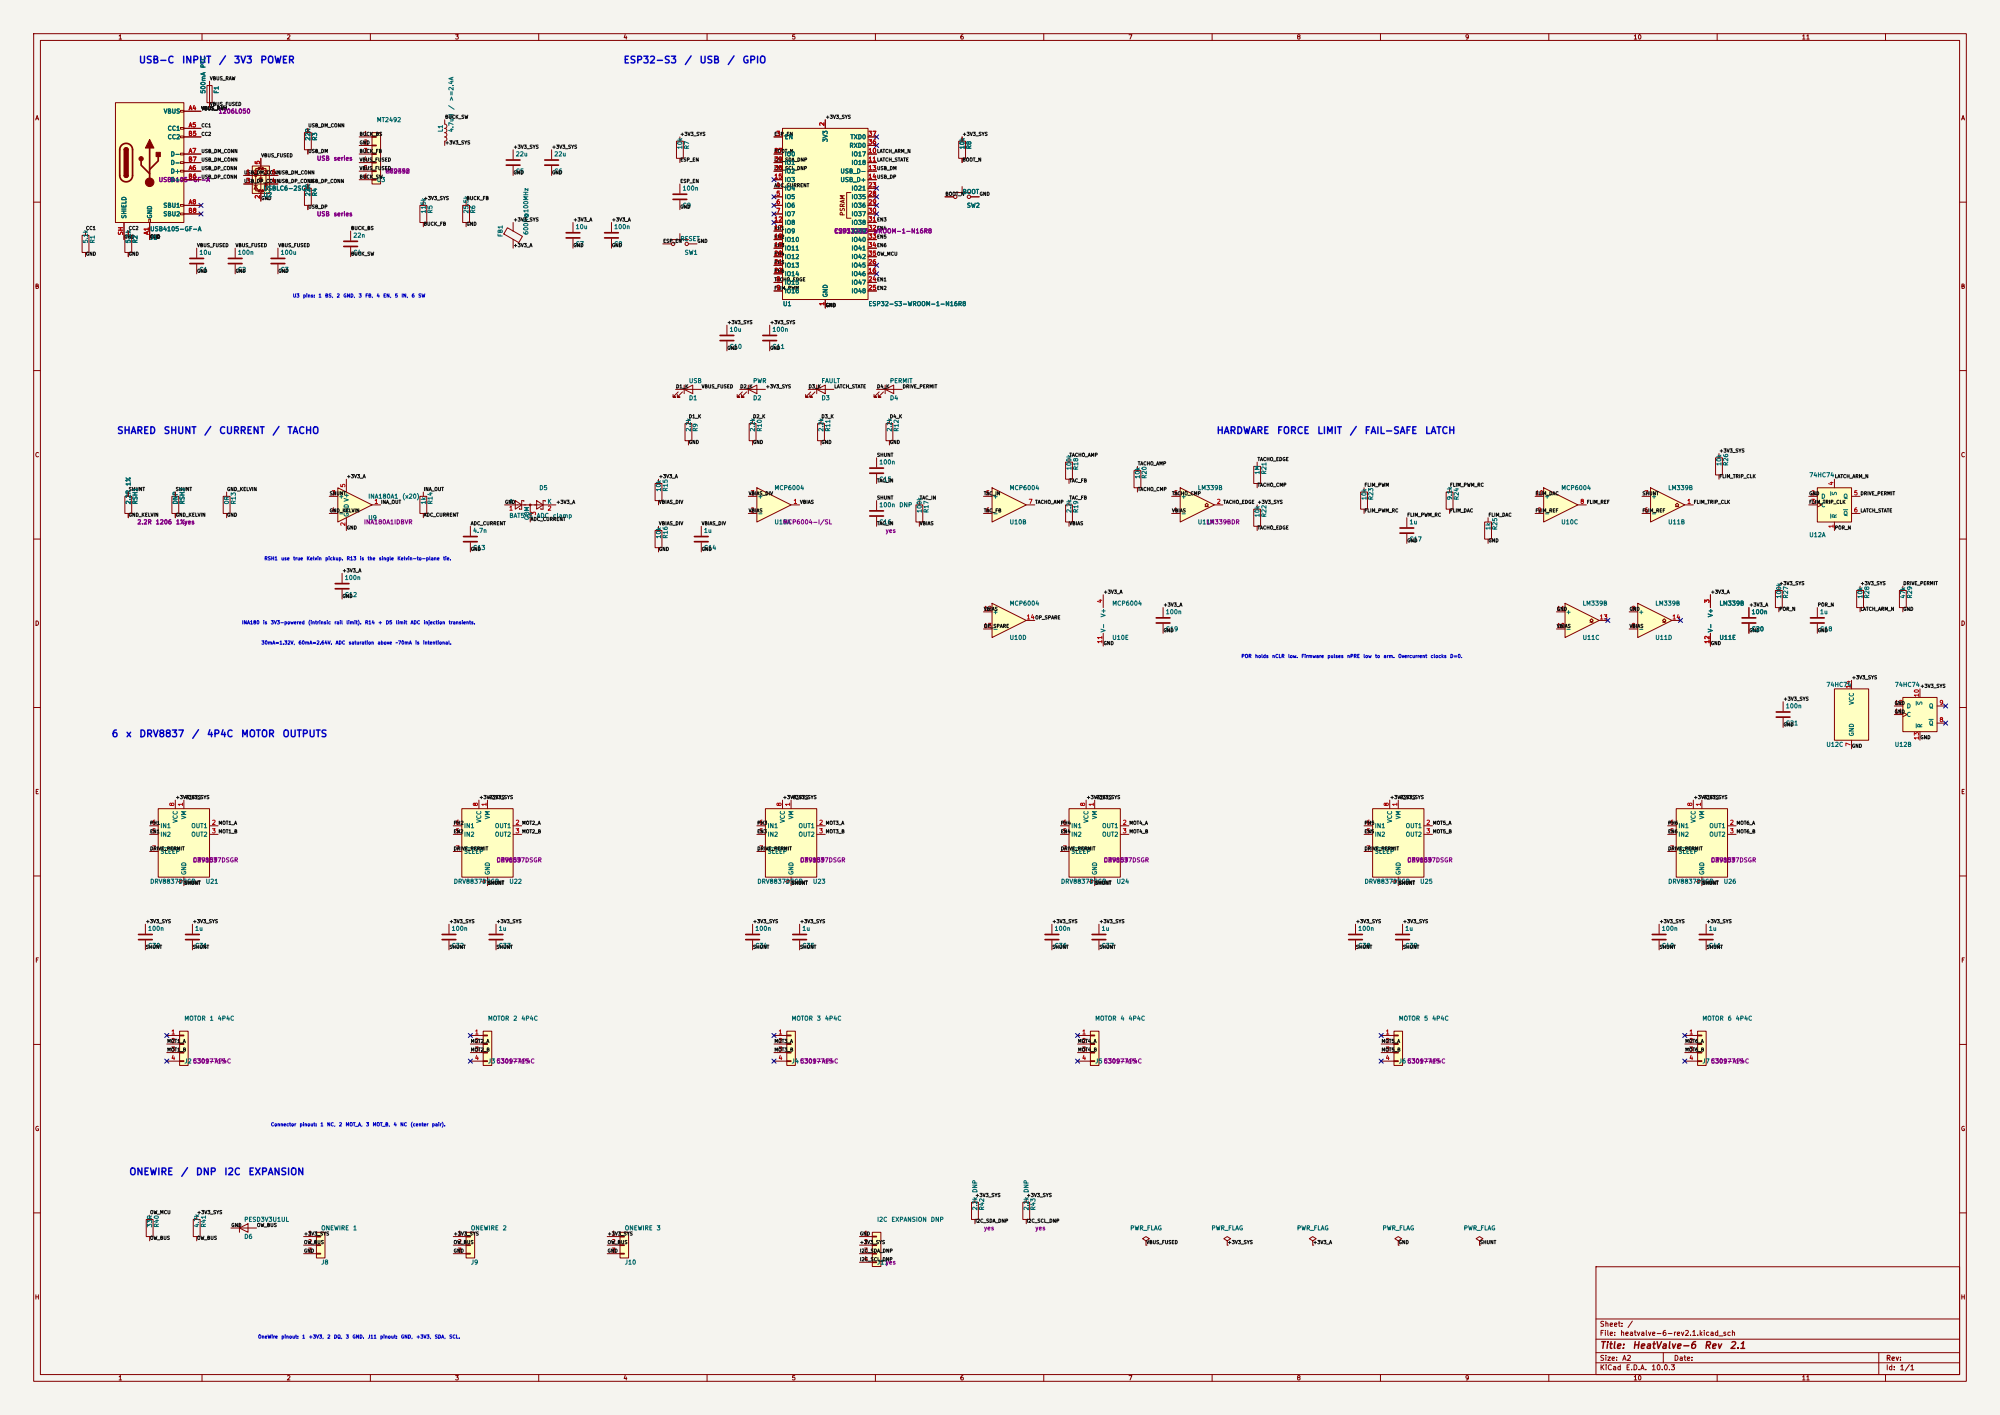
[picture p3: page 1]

U3 pins: 1 BS, 2 GND, 3 FB, 4 EN, 5 IN, 6 SW

SHARED SHUNT / CURRENT / TACHO

HARDWARE FORCE LIMIT / FAIL-SAFE LATCH

30mA=1.32V, 60mA=2.64V. ADC saturation above ~70mA is intentional. RSH1 use true Kelvin pickup. R13 is the single Kelvin-to-plane tie.

INA180 is 3V3-powered (intrinsic rail limit). R14 + D5 limit ADC injection transients.

POR holds nCLR low. Firmware pulses nPRE low to arm. Overcurrent clocks D=0. ONEWIRE / DNP I2C EXPANSION

Connector pinout: 1 NC, 2 MOT_A, 3 MOT_B, 4 NC (center pair).

OneWire pinout: 1 +3V3, 2 DQ, 3 GND. J11 pinout: GND, +3V3, SDA, SCL.

Size: A2 | Rev:
KiCad E.D.A. 10.0.3 | Id: 1/1

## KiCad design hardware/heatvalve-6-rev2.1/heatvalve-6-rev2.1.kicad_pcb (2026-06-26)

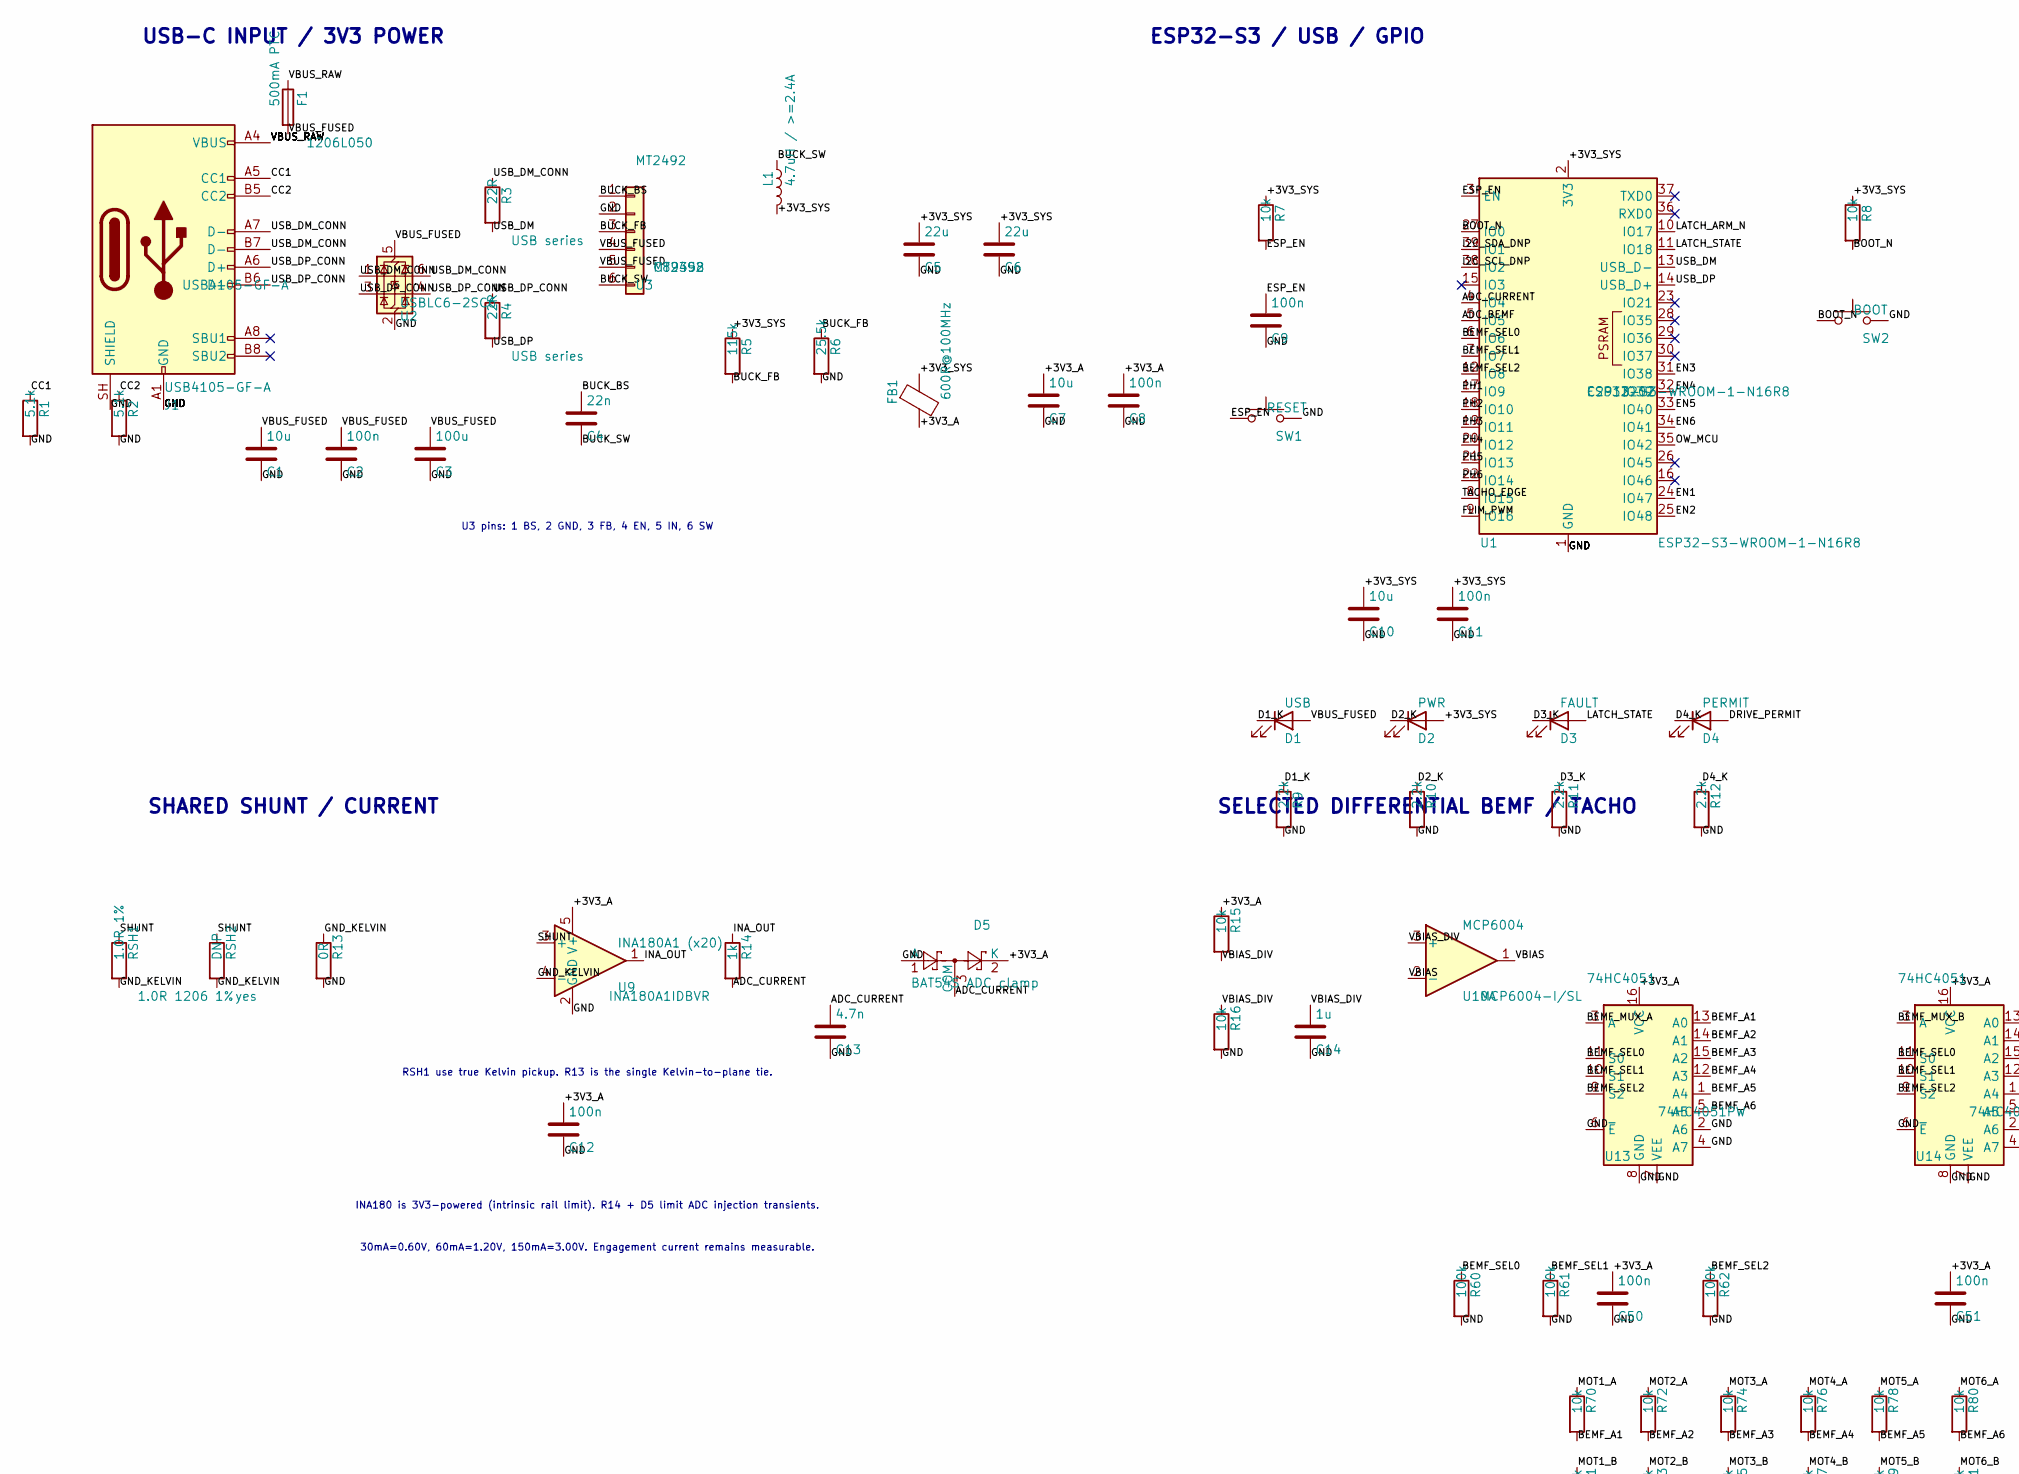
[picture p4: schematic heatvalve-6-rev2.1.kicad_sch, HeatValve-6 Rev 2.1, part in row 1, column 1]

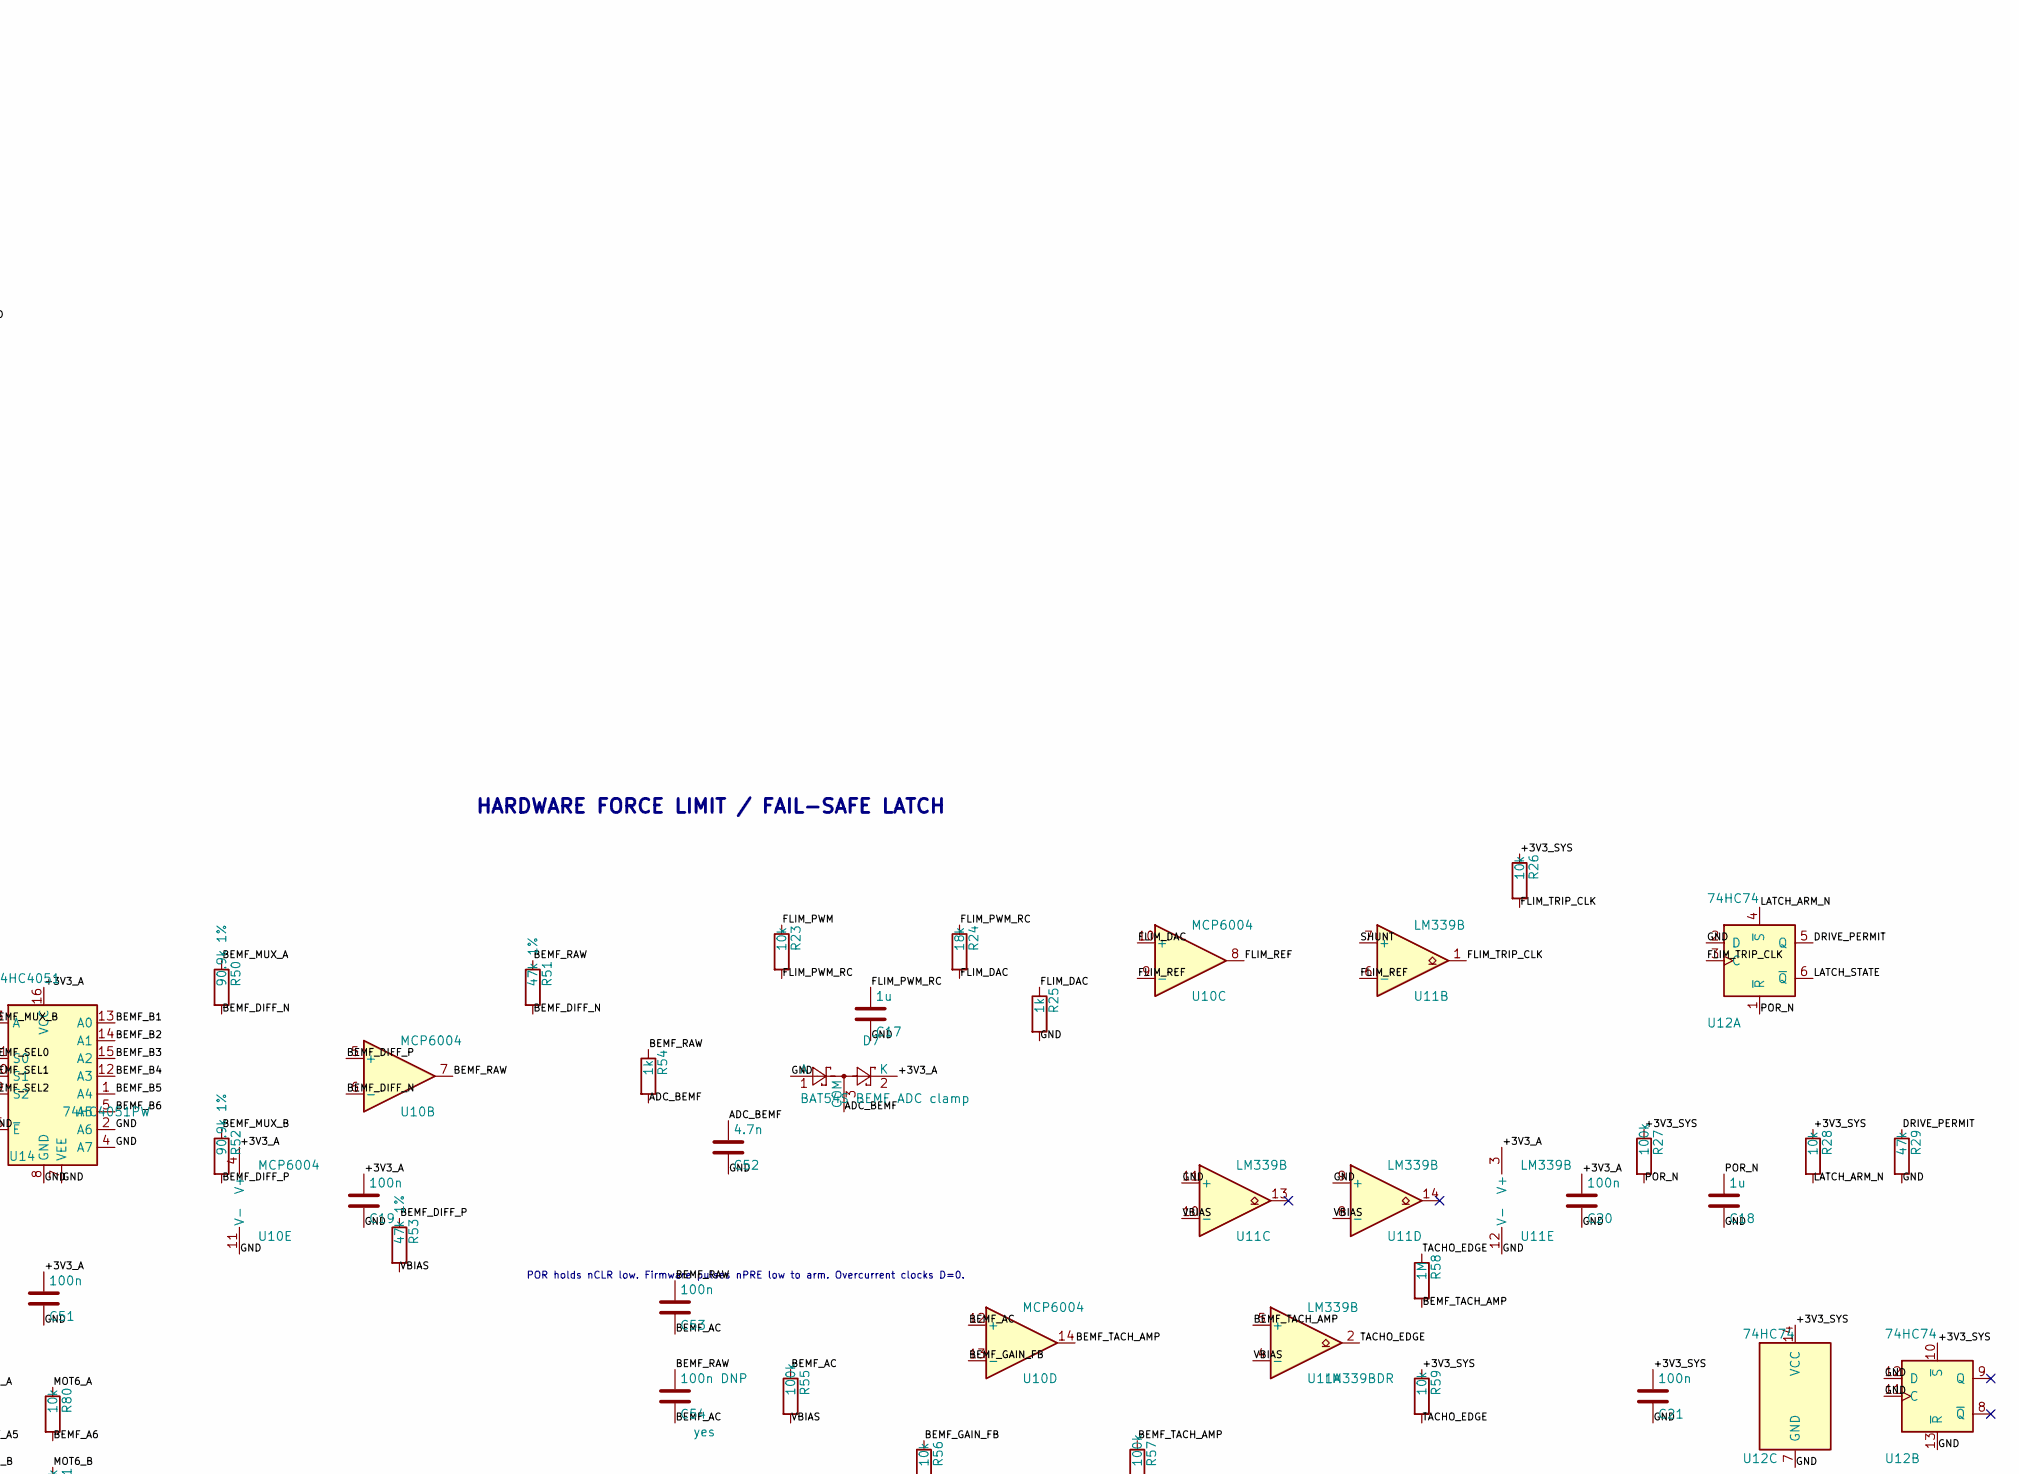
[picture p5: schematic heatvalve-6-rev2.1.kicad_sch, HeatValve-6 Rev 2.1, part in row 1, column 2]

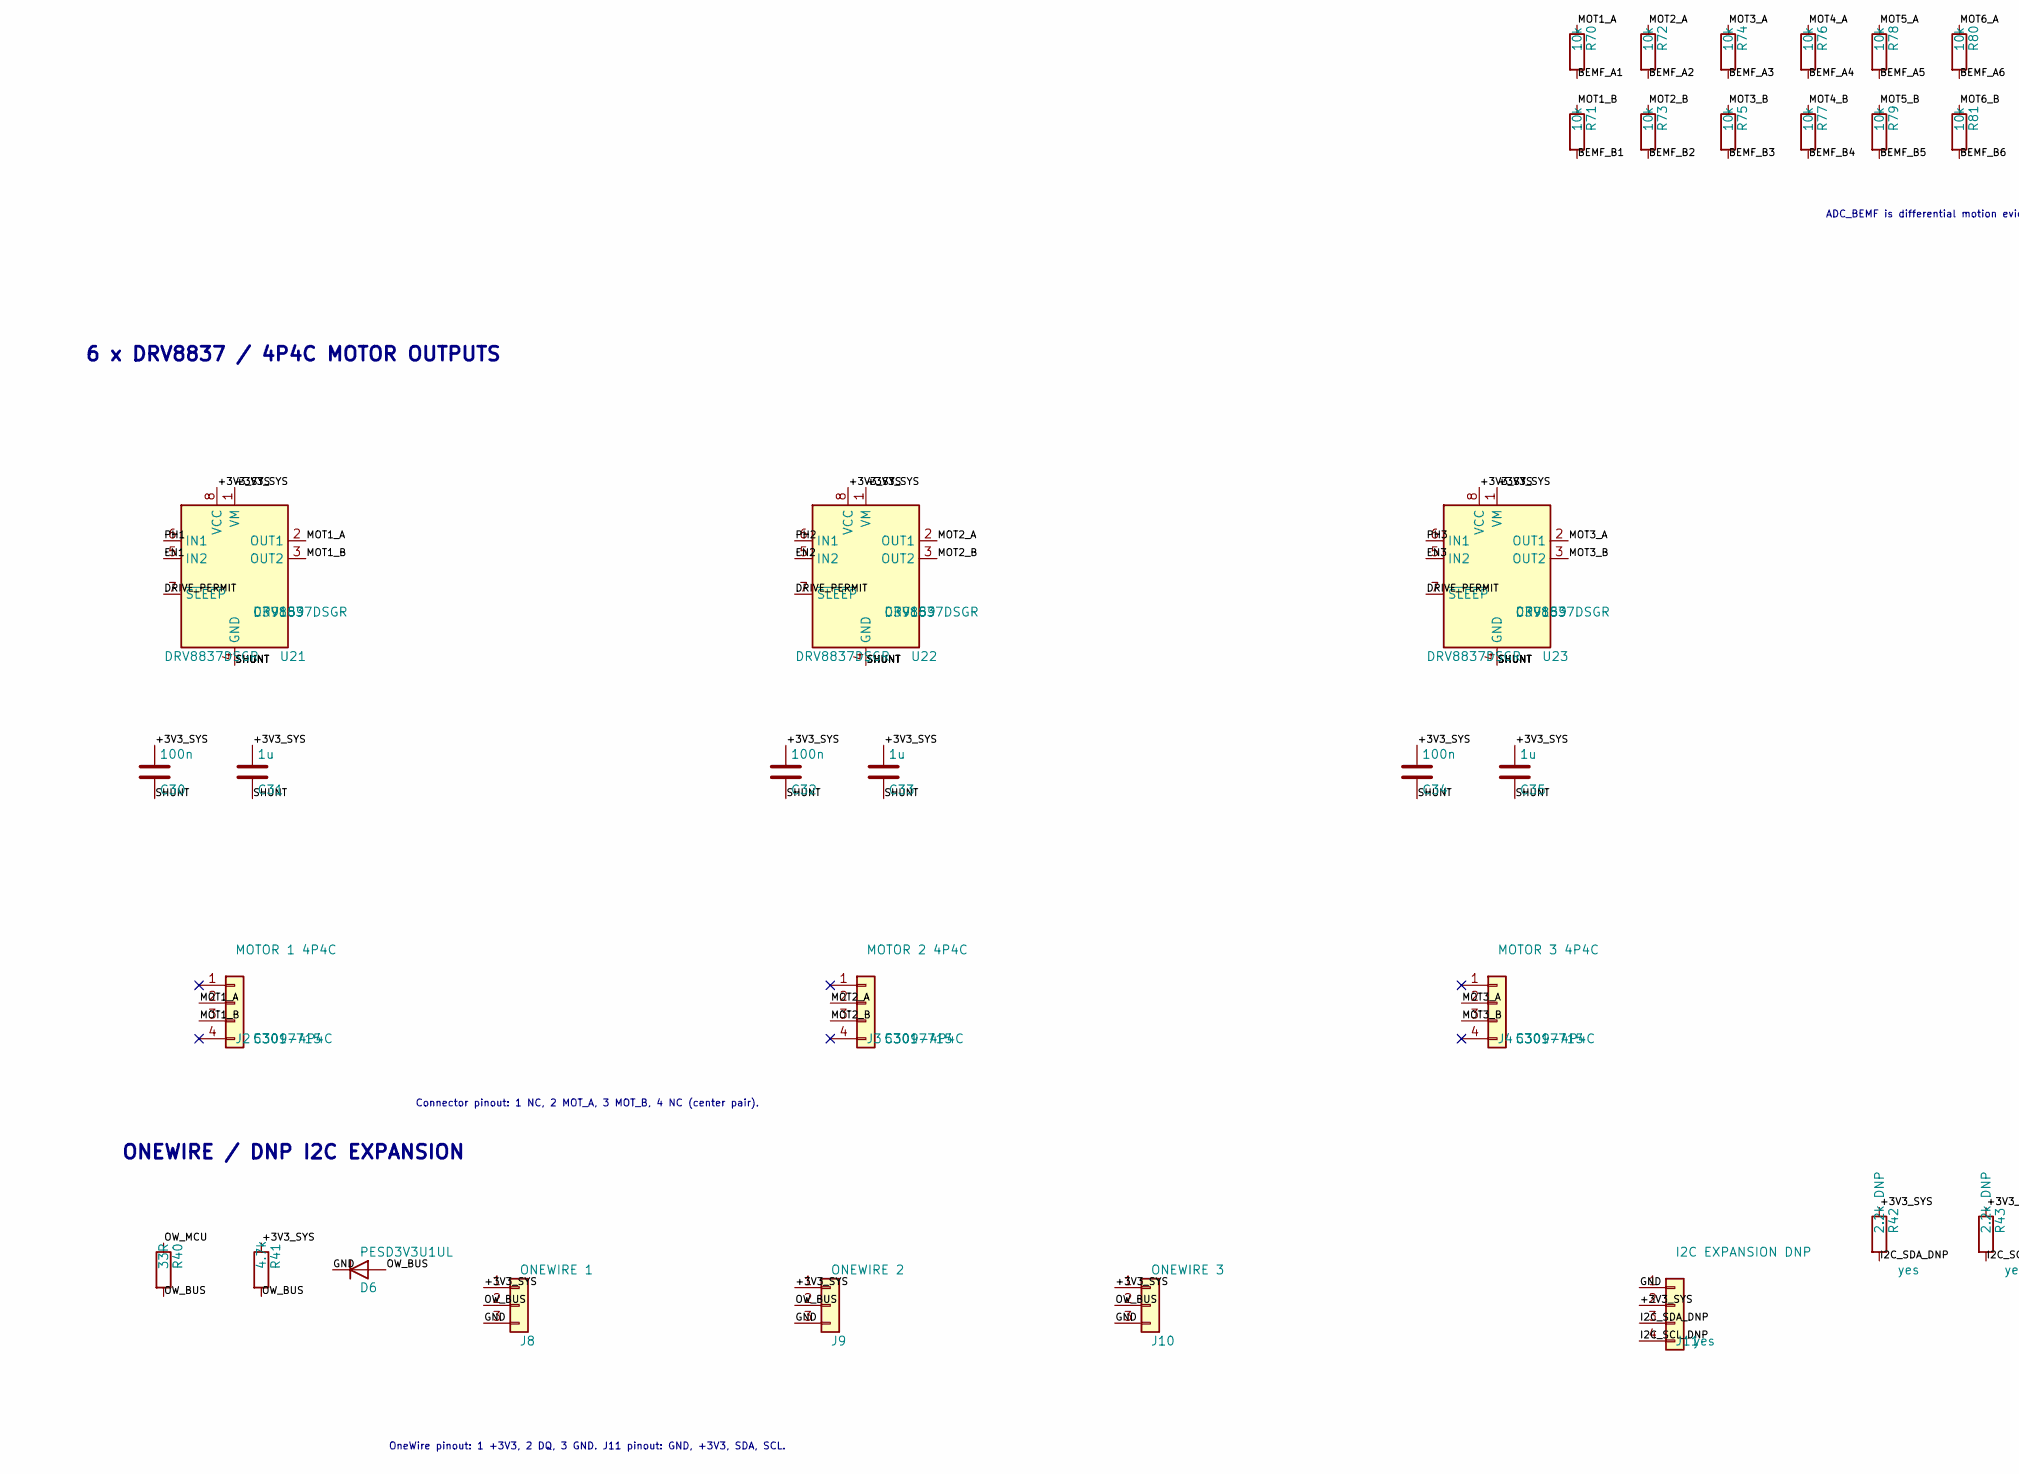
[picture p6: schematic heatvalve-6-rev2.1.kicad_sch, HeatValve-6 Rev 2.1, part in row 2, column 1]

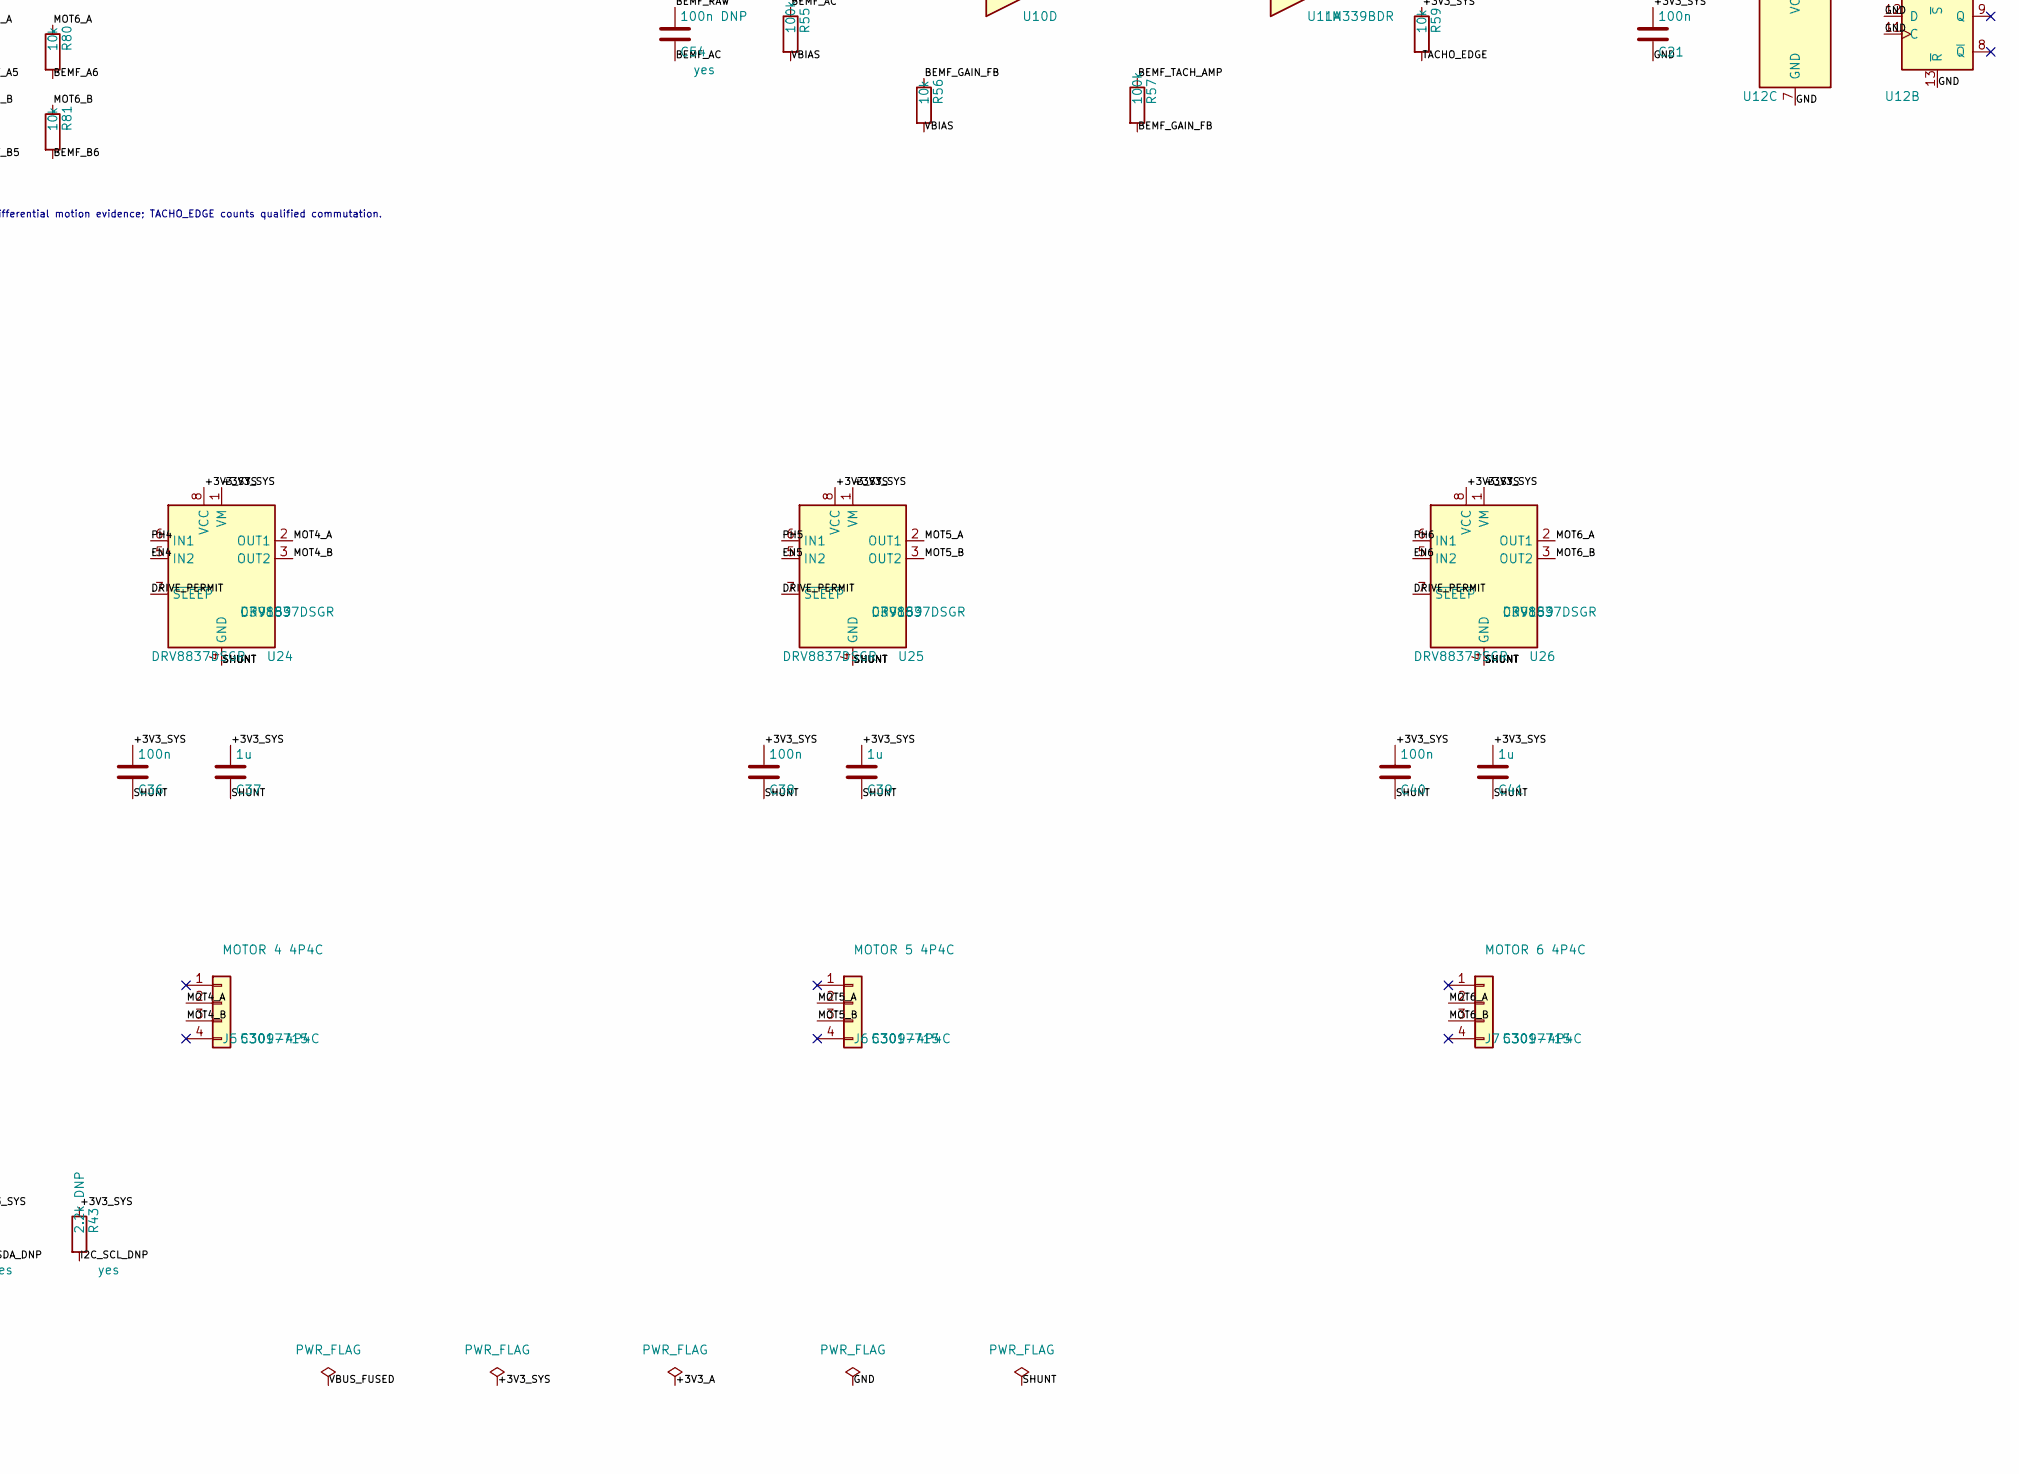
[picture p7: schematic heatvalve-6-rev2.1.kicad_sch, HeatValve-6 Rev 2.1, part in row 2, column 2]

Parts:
C1: 10u; C_0603_1608Metric
C2, C8, C9, C11, C12, C19, C20, C21, C30, C32, C34, C36, C38, C40, C50, C51, C53: 100n; C_0603_1608Metric
C3: 100u; CP_Elec_6.3x7.7
C4: 22n; C_0603_1608Metric
C5, C6: 22u; C_0805_2012Metric
C7, C10: 10u; C_0805_2012Metric
C13, C52: 4.7n; C_0603_1608Metric
C14, C17, C18: 1u; C_0603_1608Metric
C31, C33, C35, C37, C39, C41: 1u; C_0805_2012Metric
C54: 100n DNP; C_0603_1608Metric
D1: USB; LED_0603_1608Metric
D2: PWR; LED_0603_1608Metric
D3: FAULT; LED_0603_1608Metric
D4: PERMIT; LED_0603_1608Metric
D5: BAT54S ADC clamp; SOT-23
D6: PESD3V3U1UL; D_SOD-323
D7: BAT54S BEMF ADC clamp; SOT-23
F1: 500mA PTC; Fuse_1206_3216Metric; MPN 1206L050
FB1: 600R@100MHz; L_0603_1608Metric_Pad1.05x0.95mm_HandSolder
J1: USB4105-GF-A; USB_C_Receptacle_GCT_USB4105-xx-A_16P_TopMnt_Horizontal; MPN USB4105-GF-A
J2: MOTOR 1 4P4C; RJ9_Evercom_5301-440xxx_Horizontal; MPN 5301-4P4C; LCSC C3097715
J3: MOTOR 2 4P4C; RJ9_Evercom_5301-440xxx_Horizontal; MPN 5301-4P4C; LCSC C3097715
J4: MOTOR 3 4P4C; RJ9_Evercom_5301-440xxx_Horizontal; MPN 5301-4P4C; LCSC C3097715
J5: MOTOR 4 4P4C; RJ9_Evercom_5301-440xxx_Horizontal; MPN 5301-4P4C; LCSC C3097715
J6: MOTOR 5 4P4C; RJ9_Evercom_5301-440xxx_Horizontal; MPN 5301-4P4C; LCSC C3097715
J7: MOTOR 6 4P4C; RJ9_Evercom_5301-440xxx_Horizontal; MPN 5301-4P4C; LCSC C3097715
J8: ONEWIRE 1; TerminalBlock_4Ucon_1x03_P3.50mm_Horizontal
J9: ONEWIRE 2; TerminalBlock_4Ucon_1x03_P3.50mm_Horizontal
J10: ONEWIRE 3; TerminalBlock_4Ucon_1x03_P3.50mm_Horizontal
J11: I2C EXPANSION DNP; PinHeader_1x04_P2.54mm_Vertical
L1: 4.7uH / >=2.4A; L_Wuerth_HCI-5040
R1, R2: 5.1k; R_0603_1608Metric
R3, R4: 22R; R_0603_1608Metric
R5: 115k; R_0603_1608Metric
R6: 25.5k; R_0603_1608Metric
R7, R8, R15, R16, R23, R26, R28, R56, R59, R70, R71, R72, R73, R74, R75, R76, R77, R78, R79, R80, R81: 10k; R_0603_1608Metric
R9, R10, R11, R12: 2.2k; R_0603_1608Metric
R13: 0R; R_0603_1608Metric
R14, R25, R54: 1k; R_0603_1608Metric
R24: 18k; R_0603_1608Metric
R27, R55, R57, R60, R61, R62: 100k; R_0603_1608Metric
R29: 47k; R_0603_1608Metric
R40: 33R; R_0603_1608Metric
R41: 4.7k; R_0603_1608Metric
R42, R43: 2.2k DNP; R_0603_1608Metric
R50, R52: 90.9k 1%; R_0603_1608Metric
R51, R53: 47k 1%; R_0603_1608Metric
R58: 1M; R_0603_1608Metric
RSH1: 1.0R 1%; R_1206_3216Metric; MPN 1.0R 1206 1%
RSH2: DNP; R_1206_3216Metric
SW1: RESET; SW_SPST_PTS810
SW2: BOOT; SW_SPST_PTS810
U1: ESP32-S3-WROOM-1-N16R8; ESP32-S3-WROOM-1; MPN ESP32-S3-WROOM-1-N16R8; LCSC C2913202
U2: USBLC6-2SC6; SOT-23-6
U3: MT2492; SOT-23-6; MPN MT2492; LCSC C89358
U9: INA180A1 (x20); SOT-23-5; MPN INA180A1IDBVR
U10: MCP6004; SOIC-14_3.9x8.7mm_P1.27mm; MPN MCP6004-I/SL
U11: LM339B; SOIC-14_3.9x8.7mm_P1.27mm; MPN LM339BDR
U12: 74HC74; SOIC-14_3.9x8.7mm_P1.27mm
U13, U14: 74HC4051; TSSOP-16_4.4x5mm_P0.65mm; MPN 74HC4051PW
U21, U22, U23, U24, U25, U26: DRV8837DSGR; WSON-8-1EP_2x2mm_P0.5mm_EP0.9x1.6mm; MPN DRV8837DSGR; LCSC C39159

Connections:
/+3V3_A: C7.1, C8.1, C12.1, C19.1, C20.1, C50.1, C51.1, D5.2 (K), D7.2 (K), FB1.2, R15.1, U9.5 (V+), U10.4 (V+), U11.3 (V+), U13.16 (VCC), U14.16 (VCC)
/+3V3_SYS: C5.1, C6.1, C10.1, C11.1, C21.1, C30.1, C31.1, C32.1, C33.1, C34.1, C35.1, C36.1, C37.1, C38.1, C39.1, C40.1, C41.1, D2.2 (A), FB1.1, J8.1, J9.1, J10.1, J11.2, L1.2, R5.1, R7.1, R8.1, R26.1, R27.1, R28.1, R41.1, R42.1, R43.1, R59.1, U1.2 (3V3), U12.10 (~S), U12.14 (VCC), U21.1 (VM), U21.8 (VCC), U22.1 (VM), U22.8 (VCC), U23.1 (VM), U23.8 (VCC), U24.1 (VM), U24.8 (VCC), U25.1 (VM), U25.8 (VCC), U26.1 (VM), U26.8 (VCC)
/ADC_BEMF: C52.1, D7.3 (COM), R54.2, U1.5 (IO5)
/ADC_CURRENT: C13.1, D5.3 (COM), R14.2, U1.4 (IO4)
/BEMF_A1: R70.2, U13.13 (A0)
/BEMF_A2: R72.2, U13.14 (A1)
/BEMF_A3: R74.2, U13.15 (A2)
/BEMF_A4: R76.2, U13.12 (A3)
/BEMF_A5: R78.2, U13.1 (A4)
/BEMF_A6: R80.2, U13.5 (A5)
/BEMF_AC: C53.2, C54.2, R55.1, U10.12 (+)
/BEMF_B1: R71.2, U14.13 (A0)
/BEMF_B2: R73.2, U14.14 (A1)
/BEMF_B3: R75.2, U14.15 (A2)
/BEMF_B4: R77.2, U14.12 (A3)
/BEMF_B5: R79.2, U14.1 (A4)
/BEMF_B6: R81.2, U14.5 (A5)
/BEMF_DIFF_N: R50.2, R51.2, U10.6 (-)
/BEMF_DIFF_P: R52.2, R53.1, U10.5 (+)
/BEMF_GAIN_FB: R56.1, R57.2, U10.13 (-)
/BEMF_MUX_A: R50.1, U13.3 (A)
/BEMF_MUX_B: R52.1, U14.3 (A)
/BEMF_RAW: C53.1, C54.1, R51.1, R54.1, U10.7
/BEMF_SEL0: R60.1, U1.6 (IO6), U13.11 (S0), U14.11 (S0)
/BEMF_SEL1: R61.1, U1.7 (IO7), U13.10 (S1), U14.10 (S1)
/BEMF_SEL2: R62.1, U1.12 (IO8), U13.9 (S2), U14.9 (S2)
/BEMF_TACH_AMP: R57.1, R58.2, U10.14, U11.5 (+)
/BOOT_N: R8.2, SW2.1, U1.27 (IO0)
/BUCK_BS: C4.1, U3.1
/BUCK_FB: R5.2, R6.1, U3.3
/BUCK_SW: C4.2, L1.1, U3.6
/CC1: J1.A5 (CC1), R1.1
/CC2: J1.B5 (CC2), R2.1
/D1_K: D1.1 (K), R9.1
/D2_K: D2.1 (K), R10.1
/D3_K: D3.1 (K), R11.1
/D4_K: D4.1 (K), R12.1
/DRIVE_PERMIT: D4.2 (A), R29.1, U12.5 (Q), U21.7 (~SLEEP), U22.7 (~SLEEP), U23.7 (~SLEEP), U24.7 (~SLEEP), U25.7 (~SLEEP), U26.7 (~SLEEP)
/EN1: U1.24 (IO47), U21.5 (IN2)
/EN2: U1.25 (IO48), U22.5 (IN2)
/EN3: U1.31 (IO38), U23.5 (IN2)
/EN4: U1.32 (IO39), U24.5 (IN2)
/EN5: U1.33 (IO40), U25.5 (IN2)
/EN6: U1.34 (IO41), U26.5 (IN2)
/ESP_EN: C9.1, R7.2, SW1.1, U1.3 (EN)
/FLIM_DAC: R24.2, R25.1, U10.10 (+)
/FLIM_PWM: R23.1, U1.9 (IO16)
/FLIM_PWM_RC: C17.1, R23.2, R24.1
/FLIM_REF: U10.8, U10.9 (-), U11.6 (-)
/FLIM_TRIP_CLK: R26.2, U11.1, U12.3 (C)
/GND: C1.2, C2.2, C3.2, C5.2, C6.2, C7.2, C8.2, C9.2, C10.2, C11.2, C12.2, C13.2, C14.2, C17.2, C18.2, C19.2, C20.2, C21.2, C50.2, C51.2, C52.2, D5.1 (A), D6.1 (K), D7.1 (A), J1.A1 (GND), J1.A12 (GND), J1.B1 (GND), J1.B12 (GND), J1.SH (SHIELD), J8.3, J9.3, J10.3, J11.1, R1.2, R2.2, R6.2, R9.2, R10.2, R11.2, R12.2, R13.2, R16.2, R25.2, R29.2, R60.2, R61.2, R62.2, SW1.2, SW2.2, U1.1 (GND), U1.40 (GND), U1.41 (GND), U2.2 (GND), U3.2, U9.2 (GND), U10.11 (V-), U11.9 (+), U11.11 (+), U11.12 (V-), U12.2 (D), U12.7 (GND), U12.11 (C), U12.12 (D), U12.13 (~R), U13.2 (A6), U13.4 (A7), U13.6 (~E), U13.7 (VEE), U13.8 (GND), U14.2 (A6), U14.4 (A7), U14.6 (~E), U14.7 (VEE), U14.8 (GND)
/GND_KELVIN: R13.1, RSH1.2, RSH2.2, U9.4 (-)
/I2C_SCL_DNP: J11.4, R43.2, U1.38 (IO2)
/I2C_SDA_DNP: J11.3, R42.2, U1.39 (IO1)
/INA_OUT: R14.1, U9.1
/LATCH_ARM_N: R28.2, U1.10 (IO17), U12.4 (~S)
/LATCH_STATE: D3.2 (A), U1.11 (IO18), U12.6 (~Q)
/MOT1_A: J2.2, R70.1, U21.2 (OUT1)
/MOT1_B: J2.3, R71.1, U21.3 (OUT2)
/MOT2_A: J3.2, R72.1, U22.2 (OUT1)
/MOT2_B: J3.3, R73.1, U22.3 (OUT2)
/MOT3_A: J4.2, R74.1, U23.2 (OUT1)
/MOT3_B: J4.3, R75.1, U23.3 (OUT2)
/MOT4_A: J5.2, R76.1, U24.2 (OUT1)
/MOT4_B: J5.3, R77.1, U24.3 (OUT2)
/MOT5_A: J6.2, R78.1, U25.2 (OUT1)
/MOT5_B: J6.3, R79.1, U25.3 (OUT2)
/MOT6_A: J7.2, R80.1, U26.2 (OUT1)
/MOT6_B: J7.3, R81.1, U26.3 (OUT2)
/OW_BUS: D6.2 (A), J8.2, J9.2, J10.2, R40.2, R41.2
/OW_MCU: R40.1, U1.35 (IO42)
/PH1: U1.17 (IO9), U21.6 (IN1)
/PH2: U1.18 (IO10), U22.6 (IN1)
/PH3: U1.19 (IO11), U23.6 (IN1)
/PH4: U1.20 (IO12), U24.6 (IN1)
/PH5: U1.21 (IO13), U25.6 (IN1)
/PH6: U1.22 (IO14), U26.6 (IN1)
/POR_N: C18.1, R27.2, U12.1 (~R)
/SHUNT: C30.2, C31.2, C32.2, C33.2, C34.2, C35.2, C36.2, C37.2, C38.2, C39.2, C40.2, C41.2, RSH1.1, RSH2.1, U9.3 (+), U11.7 (+), U21.4 (GND), U21.9 (GND), U22.4 (GND), U22.9 (GND), U23.4 (GND), U23.9 (GND), U24.4 (GND), U24.9 (GND), U25.4 (GND), U25.9 (GND), U26.4 (GND), U26.9 (GND)
/TACHO_EDGE: R58.1, R59.2, U1.8 (IO15), U11.2
/USB_DM: R3.2, U1.13 (USB_D-)
/USB_DM_CONN: J1.A7 (D-), J1.B7 (D-), R3.1, U2.1 (I/O1), U2.6 (I/O1)
/USB_DP: R4.2, U1.14 (USB_D+)
/USB_DP_CONN: J1.A6 (D+), J1.B6 (D+), R4.1, U2.3 (I/O2), U2.4 (I/O2)
/VBIAS: R53.2, R55.2, R56.2, U10.1, U10.2 (-), U11.4 (-), U11.8 (-), U11.10 (-)
/VBIAS_DIV: C14.1, R15.2, R16.1, U10.3 (+)
/VBUS_FUSED: C1.1, C2.1, C3.1, D1.2 (A), F1.2, U2.5 (VBUS), U3.4, U3.5
/VBUS_RAW: F1.1, J1.A4 (VBUS), J1.A9 (VBUS), J1.B4 (VBUS), J1.B9 (VBUS)

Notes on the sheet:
USB-C INPUT / 3V3 POWER
U3 pins: 1 BS, 2 GND, 3 FB, 4 EN, 5 IN, 6 SW
ESP32-S3 / USB / GPIO
SHARED SHUNT / CURRENT
RSH1 use true Kelvin pickup. R13 is the single Kelvin-to-plane tie.
INA180 is 3V3-powered (intrinsic rail limit). R14 + D5 limit ADC injection transients.
30mA=0.60V, 60mA=1.20V, 150mA=3.00V. Engagement current remains measurable.
SELECTED DIFFERENTIAL BEMF / TACHO
ADC_BEMF is differential motion evidence; TACHO_EDGE counts qualified commutation.
HARDWARE FORCE LIMIT / FAIL-SAFE LATCH
POR holds nCLR low. Firmware pulses nPRE low to arm. Overcurrent clocks D=0.
6 x DRV8837 / 4P4C MOTOR OUTPUTS
Connector pinout: 1 NC, 2 MOT_A, 3 MOT_B, 4 NC (center pair).
ONEWIRE / DNP I2C EXPANSION
OneWire pinout: 1 +3V3, 2 DQ, 3 GND. J11 pinout: GND, +3V3, SDA, SCL.

Board: 4 copper layers, 130 parts (0 on the bottom side), 88 nets, no tracks yet.

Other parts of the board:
H1, H2: M3; MountingHole_3.2mm_M3

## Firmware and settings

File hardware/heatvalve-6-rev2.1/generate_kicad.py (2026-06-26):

#!/usr/bin/env python3
"""Generate the HeatValve-6 Rev 2.1 KiCad schematic.

Requires kicad-sch-api 0.5.6. The generated files are committed so running this
script is only needed when changing the programmatic source.
"""

from pathlib import Path
import os

os.environ.setdefault("HOME", "/private/tmp")

import kicad_sch_api as ksa


ROOT = Path(__file__).resolve().parent
OUT = ROOT / "heatvalve-6-rev2.1.kicad_sch"
KICAD_SYMBOLS = Path(
    "/Applications/KiCad/KiCad.app/Contents/SharedSupport/symbols"
)


def load_libraries():
    cache = ksa.get_symbol_cache()
    for name in (
        "74xx",
        "4xxx",
        "Amplifier_Current",
        "Amplifier_Operational",
        "Comparator",
        "Connector",
        "Connector_Generic",
        "Device",
        "Diode",
        "Driver_Motor",
        "Power_Protection",
        "RF_Module",
        "Switch",
        "power",
    ):
        path = KICAD_SYMBOLS / f"{name}.kicad_sym"
        if not cache.add_library_path(path):
            raise RuntimeError(f"Unable to load KiCad library: {path}")


sch = None


def add(lib, ref, value, pos, footprint="", unit=1, rotation=0, **fields):
    return sch.components.add(
        lib_id=lib,
        reference=ref,
        value=value,
        position=pos,
        footprint=footprint,
        unit=unit,
        rotation=rotation,
        **fields,
    )


def net(comp, pin, name):
    point = comp.get_pin_position(str(pin))
    if point is None:
        raise RuntimeError(f"Pin {comp.reference}.{pin} not found")
    # kicad-sch-api 0.5.6 mirrors symbol-local Y when calculating pin
    # positions. All symbols in this generated sheet use rotation 0, so
    # reflect the returned Y coordinate around the symbol origin.
    point_y = 2 * comp.position.y - point.y
    sch.add_label(name, position=(point.x, point_y), size=1.0)


def nc(comp, pin):
    point = comp.get_pin_position(str(pin))
    if point is None:
        raise RuntimeError(f"Pin {comp.reference}.{pin} not found")
    point_y = 2 * comp.position.y - point.y
    sch.no_connects.add(position=(point.x, point_y))


def passive(ref, value, pos, a, b, footprint="Resistor_SMD:R_0603_1608Metric", **fields):
    lib = "Device:C" if ref.startswith("C") else "Device:R"
    comp = add(lib, ref, value, pos, footprint, **fields)
    net(comp, 1, a)
    net(comp, 2, b)
    return comp


def decoupling(ref, value, pos, rail, ground="GND", footprint="Capacitor_SMD:C_0603_1608Metric"):
    return passive(ref, value, pos, rail, ground, footprint)


def section(text, pos):
    # Keep left-edge headings inside the printable A2 frame. KiCad anchors
    # schematic text at its centre rather than at the left edge.
    x, y = pos
    if x < 100:
        x += 38
    sch.add_text(text, (x, y), size=2.0, bold=True)


def note(text, pos):
    x, y = pos
    if x < 100:
        x = 105
    sch.add_text(text, (x, y), size=1.0)


def generate():
    global sch
    load_libraries()
    sch = ksa.create_schematic("HeatValve-6 Rev 2.1")

    # ------------------------------------------------------------------
    # USB-C input and 3.3 V buck supply
    # ------------------------------------------------------------------
    section("USB-C INPUT / 3V3 POWER", (25, 18))
    j1 = add(
        "Connector:USB_C_Receptacle_USB2.0_16P",
        "J1",
        "USB4105-GF-A",
        (45, 48),
        "Connector_USB:USB_C_Receptacle_GCT_USB4105-xx-A_16P_TopMnt_Horizontal",
        MPN="USB4105-GF-A",
    )
    for pin in ("A1", "A12", "B1", "B12", "SH"):
        net(j1, pin, "GND")
    for pin in ("A4", "A9", "B4", "B9"):
        net(j1, pin, "VBUS_RAW")
    net(j1, "A5", "CC1")
    net(j1, "B5", "CC2")
    for pin in ("A6", "B6"):
        net(j1, pin, "USB_DP_CONN")
    for pin in ("A7", "B7"):
        net(j1, pin, "USB_DM_CONN")
    for pin in ("A8", "B8"):
        nc(j1, pin)

    passive("R1", "5.1k", (25, 72), "CC1", "GND")
    passive("R2", "5.1k", (38, 72), "CC2", "GND")
    f1 = add("Device:Fuse", "F1", "500mA PTC", (62, 28), "Fuse:Fuse_1206_3216Metric", MPN="1206L050")
    net(f1, 1, "VBUS_RAW")
    net(f1, 2, "VBUS_FUSED")

    u2 = add(
        "Power_Protection:USBLC6-2SC6",
        "U2",
        "USBLC6-2SC6",
        (78, 52),
        "Package_TO_SOT_SMD:SOT-23-6",
    )
    for pin in (1, 6):
        net(u2, pin, "USB_DM_CONN")
    for pin in (3, 4):
        net(u2, pin, "USB_DP_CONN")
    net(u2, 2, "GND")
    net(u2, 5, "VBUS_FUSED")
    passive("R3", "22R", (92, 42), "USB_DM_CONN", "USB_DM", fields="USB series")
    passive("R4", "22R", (92, 59), "USB_DP_CONN", "USB_DP", fields="USB series")

    decoupling("C1", "10u", (58, 78), "VBUS_FUSED")
    decoupling("C2", "100n", (70, 78), "VBUS_FUSED")
    decoupling("C3", "100u", (82, 78), "VBUS_FUSED", footprint="Capacitor_SMD:CP_Elec_6.3x7.7")

    # MT2492 is represented as a 1x6 symbol; pin labels preserve the real pin names.
    u3 = add(
        "Connector_Generic:Conn_01x06",
        "U3",
        "MT2492",
        (112, 46),
        "Package_TO_SOT_SMD:SOT-23-6",
        MPN="MT2492",
        LCSC="C89358",
    )
    for pin, name in ((1, "BUCK_BS"), (2, "GND"), (3, "BUCK_FB"), (4, "VBUS_FUSED"), (5, "VBUS_FUSED"), (6, "BUCK_SW")):
        net(u3, pin, name)
    passive("C4", "22n", (104, 72), "BUCK_BS", "BUCK_SW", "Capacitor_SMD:C_0603_1608Metric")
    l1 = add("Device:L", "L1", "4.7uH / >=2.4A", (132, 40), "Inductor_SMD:L_Wuerth_HCI-5040")
    net(l1, 1, "BUCK_SW")
    net(l1, 2, "+3V3_SYS")
    passive("R5", "115k", (126, 64), "+3V3_SYS", "BUCK_FB")
    passive("R6", "25.5k", (139, 64), "BUCK_FB", "GND")
    decoupling("C5", "22u", (153, 48), "+3V3_SYS", footprint="Capacitor_SMD:C_0805_2012Metric")
    decoupling("C6", "22u", (164, 48), "+3V3_SYS", footprint="Capacitor_SMD:C_0805_2012Metric")
    fb1 = add("Device:FerriteBead", "FB1", "600R@100MHz", (153, 70), "Inductor_SMD:L_0603_1608Metric_Pad1.05x0.95mm_HandSolder")
    net(fb1, 1, "+3V3_SYS")
    net(fb1, 2, "+3V3_A")
    decoupling("C7", "10u", (170, 70), "+3V3_A", footprint="Capacitor_SMD:C_0805_2012Metric")
    decoupling("C8", "100n", (181, 70), "+3V3_A")
    note("U3 pins: 1 BS, 2 GND, 3 FB, 4 EN, 5 IN, 6 SW", (98, 88))

    # ------------------------------------------------------------------
    # ESP32-S3, buttons and status LEDs
    # ------------------------------------------------------------------
    section("ESP32-S3 / USB / GPIO", (205, 18))
    u1 = add(
        "RF_Module:ESP32-S3-WROOM-1",
        "U1",
        "ESP32-S3-WROOM-1-N16R8",
        (245, 64),
        "RF_Module:ESP32-S3-WROOM-1",
        MPN="ESP32-S3-WROOM-1-N16R8",
        LCSC="C2913202",
    )
    for pin in (1, 40, 41):
        net(u1, pin, "GND")
    net(u1, 2, "+3V3_SYS")
    gpio_nets = {
        3: "ESP_EN", 4: "ADC_CURRENT", 5: "ADC_BEMF",
        6: "BEMF_SEL0", 7: "BEMF_SEL1", 8: "TACHO_EDGE", 9: "FLIM_PWM",
        10: "LATCH_ARM_N", 11: "LATCH_STATE", 13: "USB_DM", 14: "USB_DP",
        17: "PH1", 18: "PH2", 19: "PH3", 20: "PH4", 21: "PH5", 22: "PH6",
        24: "EN1", 25: "EN2", 31: "EN3", 32: "EN4", 33: "EN5", 34: "EN6",
        35: "OW_MCU", 27: "BOOT_N", 12: "BEMF_SEL2",
        38: "I2C_SCL_DNP", 39: "I2C_SDA_DNP",
    }
    for pin, name in gpio_nets.items():
        net(u1, pin, name)
    for pin in (15, 16, 23, 26, 28, 29, 30, 36, 37):
        nc(u1, pin)

    passive("R7", "10k", (202, 45), "+3V3_SYS", "ESP_EN")
    decoupling("C9", "100n", (202, 58), "ESP_EN")
    sw1 = add("Switch:SW_Push", "SW1", "RESET", (202, 72), "Button_Switch_SMD:SW_SPST_PTS810")
    net(sw1, 1, "ESP_EN"); net(sw1, 2, "GND")
    passive("R8", "10k", (286, 45), "+3V3_SYS", "BOOT_N")
    sw2 = add("Switch:SW_Push", "SW2", "BOOT", (286, 58), "Button_Switch_SMD:SW_SPST_PTS810")
    net(sw2, 1, "BOOT_N"); net(sw2, 2, "GND")
    decoupling("C10", "10u", (216, 100), "+3V3_SYS", footprint="Capacitor_SMD:C_0805_2012Metric")
    decoupling("C11", "100n", (228, 100), "+3V3_SYS")

    led_data = (
        ("D1", "USB", "VBUS_FUSED", "R9", (204, 116)),
        ("D2", "PWR", "+3V3_SYS", "R10", (224, 116)),
        ("D3", "FAULT", "LATCH_STATE", "R11", (244, 116)),
        ("D4", "PERMIT", "DRIVE_PERMIT", "R12", (264, 116)),
    )
    for dref, value, source, rref, pos in led_data:
        led = add("Device:LED", dref, value, pos, "LED_SMD:LED_0603_1608Metric")
        net(led, 2, source); net(led, 1, f"{dref}_K")
        passive(rref, "2.2k", (pos[0], pos[1] + 12), f"{dref}_K", "GND")

    # ------------------------------------------------------------------
    # Shared shunt, x20 current measurement and protected ADC
    # ------------------------------------------------------------------
    section("SHARED SHUNT / CURRENT", (25, 128))
    passive("RSH1", "1.0R 1%", (38, 150), "SHUNT", "GND_KELVIN", "Resistor_SMD:R_1206_3216Metric", MPN="1.0R 1206 1%")
    passive("RSH2", "DNP", (52, 150), "SHUNT", "GND_KELVIN", "Resistor_SMD:R_1206_3216Metric", DNP="yes")
    passive("R13", "0R", (67, 150), "GND_KELVIN", "GND")
    note("RSH1 use true Kelvin pickup. R13 is the single Kelvin-to-plane tie.", (25, 166))

    u9 = add("Amplifier_Current:INA180A1", "U9", "INA180A1 (x20)", (105, 150), "Package_TO_SOT_SMD:SOT-23-5", MPN="INA180A1IDBVR")
    net(u9, 3, "SHUNT"); net(u9, 4, "GND_KELVIN"); net(u9, 1, "INA_OUT")
    net(u9, 5, "+3V3_A"); net(u9, 2, "GND")
    decoupling("C12", "100n", (102, 174), "+3V3_A")
    passive("R14", "1k", (126, 150), "INA_OUT", "ADC_CURRENT")
    decoupling("C13", "4.7n", (140, 160), "ADC_CURRENT")
    u13 = add("Diode:BAT54S", "D5", "BAT54S ADC clamp", (158, 150), "Package_TO_SOT_SMD:SOT-23")
    net(u13, 1, "GND"); net(u13, 2, "+3V3_A"); net(u13, 3, "ADC_CURRENT")
    note("INA180 is 3V3-powered (intrinsic rail limit). R14 + D5 limit ADC injection transients.", (90, 185))
    note("30mA=0.60V, 60mA=1.20V, 150mA=3.00V. Engagement current remains measurable.", (90, 191))

    # Mid-rail reference for the bidirectional differential BEMF front end.
    passive("R15", "10k", (196, 146), "+3V3_A", "VBIAS_DIV")
    passive("R16", "10k", (196, 160), "VBIAS_DIV", "GND")
    decoupling("C14", "1u", (208, 160), "VBIAS_DIV")
    u10a = add("Amplifier_Operational:MCP6004", "U10", "MCP6004", (230, 150), "Package_SO:SOIC-14_3.9x8.7mm_P1.27mm", unit=1, MPN="MCP6004-I/SL")
    net(u10a, 3, "VBIAS_DIV"); net(u10a, 2, "VBIAS"); net(u10a, 1, "VBIAS")

    # ------------------------------------------------------------------
    # Selected differential motor BEMF: independent motion/position channel
    # ------------------------------------------------------------------
    section("SELECTED DIFFERENTIAL BEMF / TACHO", (225, 128))
    mux_fp = "Package_SO:TSSOP-16_4.4x5mm_P0.65mm"
    bemf_mux = {}
    for ref, suffix, x in (("U13", "A", 255), ("U14", "B", 300)):
        mux = add("74xx:74HC4051", ref, "74HC4051", (x, 166), mux_fp,
                  MPN="74HC4051PW")
        bemf_mux[suffix] = mux
        # Common, enable, supplies, then three binary select inputs.
        net(mux, 3, f"BEMF_MUX_{suffix}")
        net(mux, 6, "GND"); net(mux, 7, "GND"); net(mux, 8, "GND")
        net(mux, 9, "BEMF_SEL2"); net(mux, 10, "BEMF_SEL1"); net(mux, 11, "BEMF_SEL0")
        net(mux, 16, "+3V3_A")
        # Codes 6/7 are deliberately quiet if firmware selects an invalid channel.
        net(mux, 2, "GND"); net(mux, 4, "GND")
    decoupling("C50", "100n", (252, 198), "+3V3_A")
    decoupling("C51", "100n", (300, 198), "+3V3_A")
    passive("R60", "100k", (230, 198), "BEMF_SEL0", "GND")
    passive("R61", "100k", (242, 198), "BEMF_SEL1", "GND")
    passive("R62", "100k", (266, 198), "BEMF_SEL2", "GND")

    # Each exposed motor terminal is current-limited before entering the mux.
    mux_pins = (13, 14, 15, 12, 1, 5)
    for idx, pin in enumerate(mux_pins, 1):
        passive(f"R{68 + idx * 2}", "10k", (235 + idx * 11, 215),
                f"MOT{idx}_A", f"BEMF_A{idx}")
        passive(f"R{69 + idx * 2}", "10k", (235 + idx * 11, 226),
                f"MOT{idx}_B", f"BEMF_B{idx}")
        net(bemf_mux["A"], pin, f"BEMF_A{idx}")
        net(bemf_mux["B"], pin, f"BEMF_B{idx}")

    # 10k terminal resistors + 90.9k/47k network give ~0.466 differential gain.
    u10b = add("Amplifier_Operational:MCP6004", "U10", "MCP6004", (350, 166), "Package_SO:SOIC-14_3.9x8.7mm_P1.27mm", unit=2)
    passive("R50", "90.9k 1%", (325, 154), "BEMF_MUX_A", "BEMF_DIFF_N")
    passive("R51", "47k 1%", (369, 154), "BEMF_RAW", "BEMF_DIFF_N")
    passive("R52", "90.9k 1%", (325, 178), "BEMF_MUX_B", "BEMF_DIFF_P")
    passive("R53", "47k 1%", (350, 190), "BEMF_DIFF_P", "VBIAS")
    net(u10b, 5, "BEMF_DIFF_P"); net(u10b, 6, "BEMF_DIFF_N"); net(u10b, 7, "BEMF_RAW")

    # Raw ADC preserves waveforms for calibration; the separate AC path drives PCNT.
    passive("R54", "1k", (386, 166), "BEMF_RAW", "ADC_BEMF")
    decoupling("C52", "4.7n", (398, 177), "ADC_BEMF")
    d7 = add("Diode:BAT54S", "D7", "BAT54S BEMF ADC clamp", (414, 166), "Package_TO_SOT_SMD:SOT-23")
    net(d7, 1, "GND"); net(d7, 2, "+3V3_A"); net(d7, 3, "ADC_BEMF")

    passive("C53", "100n", (390, 200), "BEMF_RAW", "BEMF_AC",
            "Capacitor_SMD:C_0603_1608Metric")
    passive("C54", "100n DNP", (390, 212), "BEMF_RAW", "BEMF_AC",
            "Capacitor_SMD:C_0603_1608Metric", DNP="yes")
    passive("R55", "100k", (406, 212), "BEMF_AC", "VBIAS")
    u10d = add("Amplifier_Operational:MCP6004", "U10", "MCP6004", (440, 205), "Package_SO:SOIC-14_3.9x8.7mm_P1.27mm", unit=4)
    net(u10d, 12, "BEMF_AC"); net(u10d, 13, "BEMF_GAIN_FB"); net(u10d, 14, "BEMF_TACH_AMP")
    passive("R56", "10k", (425, 222), "BEMF_GAIN_FB", "VBIAS")
    passive("R57", "100k", (456, 222), "BEMF_TACH_AMP", "BEMF_GAIN_FB")

    u11a = add("Comparator:LM339", "U11", "LM339B", (480, 205), "Package_SO:SOIC-14_3.9x8.7mm_P1.27mm", unit=1, MPN="LM339BDR")
    net(u11a, 5, "BEMF_TACH_AMP"); net(u11a, 4, "VBIAS"); net(u11a, 2, "TACHO_EDGE")
    passive("R58", "1M", (496, 195), "TACHO_EDGE", "BEMF_TACH_AMP")
    passive("R59", "10k", (496, 212), "+3V3_SYS", "TACHO_EDGE")
    note("ADC_BEMF is differential motion evidence; TACHO_EDGE counts qualified commutation.", (315, 238))

    # ------------------------------------------------------------------
    # PWM threshold, raw-shunt comparator and fail-safe latch
    # ------------------------------------------------------------------
    section("HARDWARE FORCE LIMIT / FAIL-SAFE LATCH", (395, 128))
    passive("R23", "10k", (405, 148), "FLIM_PWM", "FLIM_PWM_RC")
    decoupling("C17", "1u", (418, 158), "FLIM_PWM_RC")
    passive("R24", "18k", (430, 148), "FLIM_PWM_RC", "FLIM_DAC")
    passive("R25", "1k", (442, 158), "FLIM_DAC", "GND")
    u10c = add("Amplifier_Operational:MCP6004", "U10", "MCP6004", (463, 150), "Package_SO:SOIC-14_3.9x8.7mm_P1.27mm", unit=3)
    net(u10c, 10, "FLIM_DAC"); net(u10c, 9, "FLIM_REF"); net(u10c, 8, "FLIM_REF")

    u11b = add("Comparator:LM339", "U11", "LM339B", (495, 150), "Package_SO:SOIC-14_3.9x8.7mm_P1.27mm", unit=2)
    net(u11b, 7, "SHUNT"); net(u11b, 6, "FLIM_REF"); net(u11b, 1, "FLIM_TRIP_CLK")
    passive("R26", "10k", (510, 139), "+3V3_SYS", "FLIM_TRIP_CLK")

    u12a = add("74xx:74HC74", "U12", "74HC74", (545, 150), "Package_SO:SOIC-14_3.9x8.7mm_P1.27mm", unit=1)
    for pin, name in ((1, "POR_N"), (2, "GND"), (3, "FLIM_TRIP_CLK"), (4, "LATCH_ARM_N"), (5, "DRIVE_PERMIT"), (6, "LATCH_STATE")):
        net(u12a, pin, name)
    passive("R27", "100k", (528, 178), "+3V3_SYS", "POR_N")
    decoupling("C18", "1u", (540, 184), "POR_N")
    passive("R28", "10k", (552, 178), "+3V3_SYS", "LATCH_ARM_N")
    passive("R29", "47k", (565, 178), "DRIVE_PERMIT", "GND")
    note("POR holds nCLR low. Firmware pulses nPRE low to arm. Overcurrent clocks D=0.", (400, 195))

    # Safely terminate unused comparator/flip-flop sections and add power units.
    u10p = add("Amplifier_Operational:MCP6004", "U10", "MCP6004", (330, 184), "Package_SO:SOIC-14_3.9x8.7mm_P1.27mm", unit=5)
    net(u10p, 4, "+3V3_A"); net(u10p, 11, "GND")
    decoupling("C19", "100n", (345, 184), "+3V3_A")

    u11c = add("Comparator:LM339", "U11", "LM339B", (470, 184), "Package_SO:SOIC-14_3.9x8.7mm_P1.27mm", unit=3)
    net(u11c, 11, "GND"); net(u11c, 10, "VBIAS"); nc(u11c, 13)
    u11d = add("Comparator:LM339", "U11", "LM339B", (492, 184), "Package_SO:SOIC-14_3.9x8.7mm_P1.27mm", unit=4)
    net(u11d, 9, "GND"); net(u11d, 8, "VBIAS"); nc(u11d, 14)
    u11p = add("Comparator:LM339", "U11", "LM339B", (510, 184), "Package_SO:SOIC-14_3.9x8.7mm_P1.27mm", unit=5)
    net(u11p, 3, "+3V3_A"); net(u11p, 12, "GND")
    decoupling("C20", "100n", (520, 184), "+3V3_A")
    u12b = add("74xx:74HC74", "U12", "74HC74", (570, 212), "Package_SO:SOIC-14_3.9x8.7mm_P1.27mm", unit=2)
    for pin, name in ((13, "GND"), (12, "GND"), (11, "GND"), (10, "+3V3_SYS")):
        net(u12b, pin, name)
    nc(u12b, 8); nc(u12b, 9)
    u12p = add("74xx:74HC74", "U12", "74HC74", (550, 212), "Package_SO:SOIC-14_3.9x8.7mm_P1.27mm", unit=3)
    net(u12p, 14, "+3V3_SYS"); net(u12p, 7, "GND")
    decoupling("C21", "100n", (530, 212), "+3V3_SYS")

    # ------------------------------------------------------------------
    # Six DRV8837 channels and 4P4C connectors
    # ------------------------------------------------------------------
    section("6 x DRV8837 / 4P4C MOTOR OUTPUTS", (25, 258))
    driver_x = (55, 145, 235, 325, 415, 505)
    for idx, x in enumerate(driver_x, 1):
        drv_ref = f"U{20 + idx}"
        conn_ref = f"J{1 + idx}"
        drv = add(
            "Driver_Motor:DRV8837", drv_ref, "DRV8837DSGR", (x, 290),
            "Package_SON:WSON-8-1EP_2x2mm_P0.5mm_EP0.9x1.6mm",
            MPN="DRV8837DSGR", LCSC="C39159",
        )
        for pin, name in ((1, "+3V3_SYS"), (2, f"MOT{idx}_A"), (3, f"MOT{idx}_B"),
                          (4, "SHUNT"), (5, f"EN{idx}"), (6, f"PH{idx}"),
                          (7, "DRIVE_PERMIT"), (8, "+3V3_SYS"), (9, "SHUNT")):
            net(drv, pin, name)
        decoupling(f"C{30 + (idx-1)*2}", "100n", (x - 12, 318), "+3V3_SYS", "SHUNT")
        decoupling(f"C{31 + (idx-1)*2}", "1u", (x + 2, 318), "+3V3_SYS", "SHUNT", "Capacitor_SMD:C_0805_2012Metric")
        conn = add(
            "Connector_Generic:Conn_01x04", conn_ref, f"MOTOR {idx} 4P4C",
            (x, 350), "Connector_RJ:RJ9_Evercom_5301-440xxx_Horizontal",
            MPN="5301-4P4C", LCSC="C3097715",
        )
        nc(conn, 1); net(conn, 2, f"MOT{idx}_A"); net(conn, 3, f"MOT{idx}_B"); nc(conn, 4)
    note("Connector pinout: 1 NC, 2 MOT_A, 3 MOT_B, 4 NC (center pair).", (25, 365))

    # ------------------------------------------------------------------
    # OneWire and DNP I2C expansion
    # ------------------------------------------------------------------
    section("ONEWIRE / DNP I2C EXPANSION", (25, 372))
    passive("R40", "33R", (45, 389), "OW_MCU", "OW_BUS")
    passive("R41", "4.7k", (58, 389), "+3V3_SYS", "OW_BUS")
    d6 = add("Device:D", "D6", "PESD3V3U1UL", (72, 389), "Diode_SMD:D_SOD-323")
    net(d6, 1, "GND"); net(d6, 2, "OW_BUS")
    for idx, x in enumerate((95, 140, 185), 8):
        conn = add(
            "Connector_Generic:Conn_01x03", f"J{idx}", f"ONEWIRE {idx-7}", (x, 394),
            "TerminalBlock_4Ucon:TerminalBlock_4Ucon_1x03_P3.50mm_Horizontal",
        )
        net(conn, 1, "+3V3_SYS"); net(conn, 2, "OW_BUS"); net(conn, 3, "GND")

    i2c = add(
        "Connector_Generic:Conn_01x04", "J11", "I2C EXPANSION DNP", (260, 394),
        "Connector_PinHeader_2.54mm:PinHeader_1x04_P2.54mm_Vertical", DNP="yes",
    )
    net(i2c, 1, "GND"); net(i2c, 2, "+3V3_SYS"); net(i2c, 3, "I2C_SDA_DNP"); net(i2c, 4, "I2C_SCL_DNP")
    passive("R42", "2.2k DNP", (290, 384), "+3V3_SYS", "I2C_SDA_DNP", DNP="yes")
    passive("R43", "2.2k DNP", (305, 384), "+3V3_SYS", "I2C_SCL_DNP", DNP="yes")
    note("OneWire pinout: 1 +3V3, 2 DQ, 3 GND. J11 pinout: GND, +3V3, SDA, SCL.", (25, 414))

    # Power flags quiet power-input ERC while preserving explicit rail names.
    for idx, (rail, x) in enumerate((("VBUS_FUSED", 340), ("+3V3_SYS", 365), ("+3V3_A", 390), ("GND", 415), ("SHUNT", 440)), 1):
        flag = add("power:PWR_FLAG", f"#FLG0{idx}", "PWR_FLAG", (x, 405))
        net(flag, 1, rail)

    sch.save(OUT)
    # Use A2 landscape so the complete review schematic remains legible on one page.
    text = OUT.read_text()
    text = text.replace('(paper "A4")', '(paper "A2")')
    OUT.write_text(text)
    print(f"Generated {OUT}")


if __name__ == "__main__":
    generate()

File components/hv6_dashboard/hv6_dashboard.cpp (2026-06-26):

#include "hv6_dashboard.h"

#include "esphome/core/log.h"
#ifdef USE_LOGGER
#include "esphome/components/logger/logger.h"
#endif
#ifdef USE_HV6_ASGARD_BRIDGE
#include "../hv6_asgard_bridge/hv6_asgard_bridge.h"
#endif
#ifdef USE_HV6_FORECAST
#include "../hv6_forecast/hv6_forecast.h"
#endif
#include <algorithm>
#include <cmath>
#include <cstdio>
#include <cstdlib>
#include <cstring>
#include <cstdarg>
#include <ctime>
#include <esp_http_server.h>
#include <esp_heap_caps.h>
#include <esp_system.h>

namespace esphome {
namespace hv6_dashboard {

static const char *const TAG = "hv6_dashboard";

namespace {

bool appendf(char *buffer, size_t capacity, size_t &offset, const char *fmt, ...) {
  if (offset >= capacity)
    return false;

  va_list args;
  va_start(args, fmt);
  const int written = vsnprintf(buffer + offset, capacity - offset, fmt, args);
  va_end(args);

  if (written < 0)
    return false;
  if (static_cast<size_t>(written) >= capacity - offset) {
    offset = capacity;
    return false;
  }

  offset += static_cast<size_t>(written);
  return true;
}

// Append `s` as the body of a JSON string (without surrounding quotes),
// escaping the characters JSON requires. Control chars become spaces.
void append_json_escaped(char *buffer, size_t capacity, size_t &offset, const char *s) {
  for (const char *p = s; p != nullptr && *p != '\0'; ++p) {
    if (offset + 2 >= capacity)
      return;
    const unsigned char c = static_cast<unsigned char>(*p);
    if (c == '"' || c == '\\') {
      buffer[offset++] = '\\';
      buffer[offset++] = static_cast<char>(c);
    } else if (c < 0x20) {
      buffer[offset++] = ' ';
    } else {
      buffer[offset++] = static_cast<char>(c);
    }
  }
}

void format_float_token(char *buffer, size_t capacity, float value, int decimals = 1) {
  if (!std::isfinite(value)) {
    snprintf(buffer, capacity, "null");
    return;
  }

  long scale = 1;
  for (int i = 0; i < decimals; i++)
    scale *= 10;

  const long scaled = lroundf(value * static_cast<float>(scale));
  const long whole = scaled / scale;
  const long fraction = std::labs(scaled % scale);

  if (decimals <= 0) {
    snprintf(buffer, capacity, "%ld", whole);
    return;
  }

  char frac_fmt[8];
  snprintf(frac_fmt, sizeof(frac_fmt), "%%0%dld", decimals);
  char frac_buf[16];
  snprintf(frac_buf, sizeof(frac_buf), frac_fmt, fraction);
  snprintf(buffer, capacity, "%ld.%s", whole, frac_buf);
}

void sanitize_text(const std::string &src, char *buffer, size_t capacity) {
  if (capacity == 0)
    return;

  size_t out = 0;
  for (size_t i = 0; i < src.size() && out + 1 < capacity; i++) {
    const char c = src[i];
    buffer[out++] = (c == '"' || c == '\\') ? '_' : c;
  }
  buffer[out] = '\0';
}

// --- minimal JSON field extractors for POST body ---

static bool json_get_str(const char *body, const char *field, char *out, size_t out_len) {
  char pat[48];
  snprintf(pat, sizeof(pat), "\"%s\":\"", field);
  const char *p = strstr(body, pat);
  if (!p) return false;
  p += strlen(pat);
  const char *end = strchr(p, '"');
  if (!end) return false;
  const size_t len = std::min(static_cast<size_t>(end - p), out_len - 1);
  memcpy(out, p, len);
  out[len] = '\0';
  return true;
}

static bool json_get_num(const char *body, const char *field, float *out) {
  char pat[48];
  snprintf(pat, sizeof(pat), "\"%s\":", field);
  const char *p = strstr(body, pat);
  if (!p) return false;
  p += strlen(pat);
  while (*p == ' ') p++;
  if (*p == '"' || *p == '{' || *p == '[') return false;
  char *end;
  const float v = strtof(p, &end);
  if (end == p) return false;
  *out = v;
  return true;
}

// --- string → enum parsers ---

static bool parse_probe_option(const char *raw, int8_t *out) {
  if (strcasecmp(raw, "None") == 0) { *out = hv6::PROBE_UNASSIGNED; return true; }
  int n = 0;
  if (sscanf(raw, "Probe %d", &n) == 1 && n >= 1 && n <= static_cast<int>(hv6::MAX_PROBES)) {
    *out = static_cast<int8_t>(n - 1);
    return true;
  }
  return false;
}

static bool parse_temp_source(const char *raw, hv6::TempSource *out) {
  if (strcasecmp(raw, "Local Probe") == 0) { *out = hv6::TempSource::LOCAL_PROBE; return true; }
  if (strcasecmp(raw, "BLE") == 0 || strcasecmp(raw, "BLE Sensor") == 0) {
    *out = hv6::TempSource::BLE_SENSOR;
    return true;
  }
  return false;
}

static const char *dashboard_variant_str() {
  return "ble";
}

static const char *temp_source_to_dashboard_str(hv6::TempSource src) {
  switch (src) {
    case hv6::TempSource::LOCAL_PROBE:
      return "Local Probe";
    case hv6::TempSource::BLE_SENSOR:
      return "BLE";
    default:
      return "Local Probe";
  }
}
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

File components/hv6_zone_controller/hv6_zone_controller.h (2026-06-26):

// =============================================================================
// HV6 Zone Controller — ESPHome Component Header
// =============================================================================
// Zone state machine with control algorithms, hydraulic balancing, and failsafe.
// Reads temperatures from ESPHome sensors, drives valves via Hv6ValveController.
// Runs as a FreeRTOS task (10s cycle) alongside ESPHome's main loop.
// =============================================================================

#pragma once

#include "esphome/core/component.h"
#include "esphome/components/sensor/sensor.h"
#include "../hv6_config_store/hv6_config_store.h"
#include "../hv6_config_store/hv6_types.h"
#include "../hv6_valve_controller/hv6_valve_controller.h"
#include "control_algorithms.h"
#include "adaptive_balance.h"
#include "freertos/FreeRTOS.h"
#include "freertos/task.h"
#include "freertos/semphr.h"
#include "freertos/queue.h"
#include <array>
#include <atomic>
#include <string>

namespace hv6 {

struct SetpointAdjustment {
  uint8_t zone;
  float offset_c;
};

/// Command received from Helios-3 optimizer for a single zone.
/// All temporal validation (valid_until, preheat windows) is performed by the
/// Helios client before writing here; the zone controller only applies the values.
struct HeliosZoneCommand {
  float setpoint_offset_c = 0.0f;  ///< Setpoint offset; zone controller clamps to [min_offset_c, max_offset_c]
  float preheat_floor_c = 0.0f;    ///< If > 0, effective setpoint will be at least this value
};

class Hv6ZoneController : public esphome::Component {
 public:
  float get_setup_priority() const override { return esphome::setup_priority::DATA; }
  void setup() override;
  void dump_config() override;

  // Configuration setters (from Python codegen)
  void set_config_store(Hv6ConfigStore *store) { config_store_ = store; }
  void set_valve_controller(Hv6ValveController *ctrl) { valve_controller_ = ctrl; }
  void set_cycle_interval_ms(uint32_t ms) { cycle_interval_ms_ = ms; }
  void set_probe_sensor(uint8_t probe, esphome::sensor::Sensor *sensor) {
    if (probe < MAX_PROBES)
      probe_sensors_[probe] = sensor;
  }

  // Thread-safe public API (callable from lambdas, etc.)
  ZoneSnapshot get_zone_snapshot(uint8_t zone) const;
  bool try_get_system_snapshot(SystemSnapshot *out, uint32_t timeout_ms = 25) const;
  SystemSnapshot get_system_snapshot() const;

  float get_zone_temperature(uint8_t zone) const;
  float get_valve_position(uint8_t zone) const;
  float get_manifold_flow_temperature() const;
  float get_manifold_return_temperature() const;

  void set_zone_setpoint(uint8_t zone, float setpoint_c);
  bool apply_setpoint_adjustment(uint8_t zone, float offset_c);

  // Helios-3 optimizer commands (applied on top of user setpoint)
  void apply_helios_command(uint8_t zone, const HeliosZoneCommand &cmd);
  void clear_all_helios_commands();

  /// Enable or disable a zone. Disabled zones close their valve and persist to NVS.
  void set_zone_enabled(uint8_t zone, bool enabled);
  bool is_zone_enabled(uint8_t zone) const;
  void set_control_algorithm(ControlAlgorithm algorithm);
  ControlAlgorithm get_control_algorithm() const;

  /// Manual mode: suppresses automatic valve positioning.
  /// Manual commands (open/close/calibrate via UI) still work.
  void set_manual_mode(bool enabled) { manual_mode_.store(enabled, std::memory_order_release); }
  bool is_manual_mode() const { return manual_mode_.load(std::memory_order_acquire); }

  // State machine accessors (for dashboard/diagnostics)
  ControllerState get_controller_state() const { return controller_state_.load(std::memory_order_acquire); }
  SystemConditionState get_system_condition_state() const { return system_condition_state_.load(std::memory_order_acquire); }

  void set_zone_probe(uint8_t zone, int8_t probe);
  int8_t get_zone_probe(uint8_t zone) const;
  void set_manifold_flow_probe(int8_t probe);
  int8_t get_manifold_flow_probe() const;
  void set_manifold_return_probe(int8_t probe);
  int8_t get_manifold_return_probe() const;

  // External temperature source (BLE sensor, etc.)
  void set_zone_external_temperature(uint8_t zone, float temp_c);
  float get_zone_external_temperature(uint8_t zone) const;
  void set_zone_temp_source(uint8_t zone, TempSource source);
  TempSource get_zone_temp_source(uint8_t zone) const;

  // BLE sensor (Shelly BLU H&T, BTHome, etc.)
  void set_zone_ble_mac(uint8_t zone, const std::string &mac);
  std::string get_zone_ble_mac(uint8_t zone) const;

  // Lightweight MAC match for the BLE advertise hot path (loopTask). Copies
  // only the 18-byte MAC fields — never the whole DeviceConfig — so it is safe
  // to call per advertisement. Returns the matching zone index (0..5) or -1.
  int8_t match_ble_mac(const char *mac) const;

  // BLE sensor discovery — callable from BLE advertise lambda (loopTask)
  struct BleSensorSeen {
    char mac[18];       ///< "AA:BB:CC:DD:EE:FF\0"
    char name[24];      ///< Advertised local name (scan response); "" if unknown
    float temp_c;       ///< Last parsed temperature, or NAN if not seen yet
    int8_t rssi;
    uint32_t last_ms;
  };
  static constexpr uint8_t BLE_SEEN_SLOTS = 16;
  static constexpr uint32_t BLE_SEEN_STALE_MS = 10 * 60 * 1000UL;  ///< 10 min

  // temp_c may be NAN (device seen but no temperature in this packet); name may
  // be null/empty (no scan-response name yet). Existing entries keep a known
  // name/temperature when a later packet omits it.
  void report_ble_sensor_seen(const char *mac, float temp_c, int8_t rssi, const char *name = nullptr);
  uint8_t get_ble_discovered(BleSensorSeen *out, uint8_t max) const;

  // Zone physical properties
  void set_zone_name(uint8_t zone, const std::string &name);  ///< Friendly name (persisted in ZoneConfig)
  void set_zone_area_m2(uint8_t zone, float area_m2);
  float get_zone_area_m2(uint8_t zone) const;
  void set_zone_pipe_spacing_mm(uint8_t zone, float spacing_mm);
  float get_zone_pipe_spacing_mm(uint8_t zone) const;
  void set_zone_pipe_type(uint8_t zone, PipeType type);
  PipeType get_zone_pipe_type(uint8_t zone) const;
  void set_zone_exterior_walls(uint8_t zone, uint8_t walls);
  uint8_t get_zone_exterior_walls(uint8_t zone) const;

  // Forecast preload exposure model (per zone)
  void set_zone_wind_exposure(uint8_t zone, float exposure);
  void set_zone_solar_gain(uint8_t zone, float gain);
  void set_zone_thermal_lead_h(uint8_t zone, uint8_t hours);

  // Probe role (room temperature vs return water)
  void set_zone_probe_role(uint8_t zone, ProbeRole role);
  ProbeRole get_zone_probe_role(uint8_t zone) const;

  // Zone sync (two zones in one room share setpoint + averaged temperature)
  void set_zone_sync(uint8_t zone, int8_t target_zone);
  int8_t get_zone_sync(uint8_t zone) const;
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

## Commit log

2026-03-25 Add motor supervisor component and related configurations
    - Introduced MotorSupervisor class for managing multiple DRV8215 motor drivers.
    - Added fault handling, calibration, and telemetry features for motor operations.
    - Created new deployment YAML files for testing and production setups.
    - Included .gitignore for deployment directory to exclude unnecessary files.
    - Configured ESPHome remote and local development entrypoints for easy integration.
    [drv8215-motor1-manual.yaml, motor_driver.yaml, pid.yaml]
2026-03-28 Add BLE Temperature Sensor Manager and Home Assistant Climate Listener
    - Introduced a new BLE Temperature Sensor Manager to handle BLE temperature sensors using BTHome v2 protocol.
    - Implemented passive BLE advertisement scanning and zone temperature updates.
    - Added a manual BLE scan button and persistent MAC address assignments for zones.
    - Created a Home Assistant climate listener to dynamically set zone target temperatures from HA.
    - Added a modular BTHome v2 parser for extracting various sensor data from BLE advertisements.
    - Introduced an adaptive control zone configuration allowing runtime profile selection for temperature control.
    [drv8215-motor1-manual.yaml, drv8215_test_motor1_manual.yaml, motor_driver.yaml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]
2026-03-30 feat: Integrate Ecodan heat pump with HeatValve-6 controllers
    - Added ecodan_bridge to local-mqtt.yaml for Ecodan integration.
    - Enhanced heatvalve-6.yaml with zone climate entity IDs and Ecodan settings.
    - Updated ble_sensors.yaml to manage BLE scan during OTA updates.
    - Implemented mqtt_ecodan.yaml for per-zone MQTT publishing and derived temperature calculation.
    - Created ecodan_asgard_bridge.yaml for multi-board aggregation and HTTP REST push to Asgard.
    - Added documentation for Ecodan integration, detailing architecture, setup, and MQTT topics.
    - Introduced new sensors for system derived temperature and Asgard push failures.
    - Implemented logic for calculating and publishing derived tem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
2026-03-30 Add heatvalve_balancer component for hydraulic balancing
    - Introduced a new component `heatvalve_balancer` to compute per-zone hydraulic factors based on pipe lengths, types, and floor cover thicknesses.
    - Updated deployment YAML files to include the new component in various configurations.
    - Removed the obsolete `local-mqtt.yaml` file as its functionality is now integrated into other configurations.
    - Enhanced the `heatvalve_dashboard` with additional settings for the new balancer.
    - Implemented MQTT support for zone state publishing and adjustments.
2026-04-04 Add ESP32-S3 board configuration and hardware components
    - Introduced esp32-s3.yaml for ESP32-S3 board configuration with PlatformIO options.
    - Added display.yaml for CH1115 128x64 OLED display configuration with custom layout and rendering logic.
    - Created i2c.yaml to define I2C bus settings.
    - Implemented led.yaml for WS2812 RGB status LED with various status effects and scripts.
    - Added motors.yaml for motor control GPIO settings including nSLEEP and nFAULT.
    - Introduced onewire.yaml for 1-Wire bus configuration.
    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
    [AB472339675044da-DK0101.xls, ha_motor1_test_dashboard.yaml, motor_driver.yaml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]
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2026-04-10 First real testing. Refactor code structure for improved readability and maintainability
    [ha_motor1_test_dashboard.yaml, motor_trace.yaml]
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2026-04-13 feat: update firmware version to v0.2.4 and modify zone state display logic in sensors
2026-04-13 feat: update firmware version to v0.2.5 and enable motor drivers by default during setup
2026-04-13 feat: implement timed control for valve zones with manual mode support and update firmware version to v0.3.3
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2026-04-14 feat: update close current factor in MotorConfig, enhance calibration handling in valve controller, and bump firmware version to v0.3.15
2026-04-14 feat: add per-zone motor current factor overrides and update default probe mapping; bump firmware version to v0.3.21
2026-04-14 feat: Update firmware version and enhance dashboard functionality
    - Bump firmware version to v0.4.23 in version.yaml.
    - Add learned-factor confidence color coding styles in dashboard.css.
    - Extend dashboard.js with new zone management features:
    - Introduce new buttons for resetting faults and factors for each zone.
    - Implement functionality for managing learned factors and runtime limits.
    - Add support for zone-specific motor profiles and settings.
    - Enhance UI to display learned factors and confidence levels.
    - Improve event handling for zone card interactions.
    - Update entity state management for new features.
    [motor_trace.yaml]
2026-04-16 Remove stylesheet link and add app root div in mock dashboard HTML refactor dashboard.js into reusable components.
    [ha_motor1_test_dashboard.yaml, motor_trace.yaml]
2026-04-20 fix: atomic hardening for cross-thread safety + disable hv6_web_api
    - Convert zone controller fields to std::atomic: manual_mode_, controller_state_,
    system_condition_state_, cycle_count_
    - Convert valve controller fields to std::atomic: motor_turning_, drivers_enabled_,
    current_fault_code_, calibrating_, calibration_request_, calibration_pending_mask_,
    live_ripple_count_
    - Add try_get_system_snapshot() for non-blocking snapshot access
    - Add CONFIG_HTTPD_MAX_URI_LEN=128 for reduced stack pressure
    - Disable hv6_web_api component (causes timeout issues)
    - Include dashboard UI improvements
    [hv6_zone_controller.h]
2026-04-21 dashboard: hydrate config on state load; fix subscribe/es bug; action queue
    - handle_state_() now includes all persisted config in the JSON response:
    zone enabled/setpoint/area/spacing/probe/temp_source/sync_to/pipe_type/
    zigbee_device/ble_mac/exterior_walls; global drivers_enabled,
    simple_preheat_enabled, manifold_type, manifold_flow/return_probe,
    motor_profile_default and all motor calibration numbers.
    Static buffer enlarged from 4096 to 10240 bytes.
    - Add targeted getters to Hv6ConfigStore (get_simple_preheat_enabled,
    get_manifold_type, get_probe_config, get_zone_temp_source,
    get_zone_mqtt_strings) to avoid full DeviceConfig copy on httpd stack.
    - Fix parse_temp_source to ac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
    [hv6_dashboard.cpp]
2026-04-22 feat: Implement dashboard snapshot functionality and update state handling
    - Added DashboardSnapshot struct to encapsulate sensor states and configuration.
    - Introduced update_snapshot_ method to periodically capture sensor data.
    - Refactored handle_state_ to utilize snapshot data for improved performance.
    - Updated LED configuration to use RGB order and adjusted brightness settings.
    - Changed pin naming for status LED to reflect RGB functionality.
    - Updated firmware version to v0.6.0 in version.yaml.
    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
2026-04-22 fix: Update safety timeout logic in execute_move_ for drive-to-endstop
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2026-06-12 feat: MPC roadmap phases 1-4 — API v1 migration, Asgard bridge, preheat absorption
    Phase 1 — cleanup & performance:
    - Migrate dashboard transport to /api/hv6/v1 (resource-shaped write routes
    with response envelope; state/history/ble-scan reads); remove legacy
    /dashboard/set|state|history|ble-scan routes and MQTT remnants
    (trace_publish_to_mqtt_ path, trace_sense option, stale docs)
    - Probe ROM watchdog: per-probe consecutive-miss counters + bus-fault guard
    (all mapped probes missing -> keep map); reset stays atomic because a
    partially cleared map would let index fallback duplicate ROMs
    - Per-task stack headroom diagnostics (5 min interval); drop obsolete
    json/text_sensor log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
2026-06-14 feat: phase 5 — wind-aware on-device forecast preload (hv6_forecast)
    New hv6_forecast component adds weather-forecast-driven per-zone preheating
    on the board itself, so heat can be routed to the specific facade a winter
    storm hits — something a whole-house optimizer (Odin) cannot do because it
    plans the house as a single signal.
    - forecast_model.{h,cpp} (namespace hv6fc, no ESP deps, host-testable):
    per-zone weather load = wind_exposure × wind_alignment(exterior_walls vs
    wind direction) × cold term − solar relief; compute_zone_preload scans the
    thermal_lead_h window and issues a capped setpoint offset
    - hv6_forecast component: 48 h Open-Meteo HTTPS fetch (esp_crt_bundle) on a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
    [hv6_dashboard.cpp]
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2026-06-18 Add system block diagram, adaptive balancing tests, and diagnostics components
    - Created a new system block diagram for HeatValve-6 Rev 2 in DOT format.
    - Implemented unit tests for adaptive balancing step math in C++.
    - Added a diagnostics card component to display system metrics such as CPU load and memory usage.
    - Introduced a settings card for hydraulic balancing configuration, allowing users to adjust balancing modes and parameters.
    [bom.csv, heatvalve-6-rev2.1.kicad_pcb, heatvalve-6-rev2.1.kicad_sch]
2026-06-18 feat(config): durable per-section NVS persistence; slim dead Helios config
    Global settings (control/preheat, forecast, asgard, balancing, probes, motor, system, pid, manifold) lived only in the main config blob, which is discarded on every CONFIG_VERSION bump — so they reset on each firmware update. Mirror each section to its own versioned durable NVS key (generic save_section/load_section helpers), overlaid on boot and seeded if missing, the same pattern zones/sensors already used. Each section bumps only on its own struct layout change.
    Also remove the dead external-Helios remnants: HeliosConfig slimmed to just the 'enabled' quiesce gate (host/port/mDNS/etc. were unused), and the caller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
    [hv6_types.h]
2026-06-18 fix(deps): declare json on its real ArduinoJson users (forecast/asgard)
    forecast and asgard parse JSON with ArduinoJson but never declared the json component — they only built because web_server (or the zone controller's stale dep) happened to pull it in. AUTO_LOAD json in both, and drop the vestigial json dependency from hv6_zone_controller (it builds no JSON). Prevents a config failure once the stock web_server is removed.
2026-06-18 perf(net): drop stock web_server UI; widen lwIP socket pool to 16
    The stock ESPHome web UI kept an SSE stream plus per-entity JSON for ~60 entities in scarce internal heap (free internal heap was ~15 KB). Nothing uses it — the custom dashboard and /api/hv6/v1 run on web_server_base, and HA uses the native API. Removing it frees internal heap and ~24 KB flash.
    CONFIG_LWIP_MAX_SOCKETS 10 -> 16: at 10, the dashboard httpd + lwIP control sockets consumed the whole pool, leaving none for the native API and the forecast's outbound HTTPS — accept() flooded with ENFILE (errno 23) and Open-Meteo fetches failed. 16 covers httpd + control + API + client with headroom.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
2026-06-18 feat(zones): device-persistent friendly zone names; /logs heap fix
    Zone names were browser-localStorage only (per-browser, not on the device). Wire them through ZoneConfig.name: set_zone_name() persists via the durable zones blob; the dashboard emits text-zone_N_name in /state and accepts a zone_name text setting. The frontend commits via applyZoneName() and a setEntity bridge mirrors the device value into D.zoneNames, so the existing zoneTag/zoneLabel consumers are unchanged. Names now survive updates and are consistent across browsers.
    Also: /logs allocates its ~12.8 KB ring copy from PSRAM instead of internal heap, so polling the Logs view no longer 503s (empty logs) under heap pressure.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
    [hv6_dashboard.cpp, hv6_zone_controller.h]
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2026-06-19 perf(board): free internal heap via BLE/PSRAM sdkconfig tuning
    The BLE variant idled at ~16 KB free internal heap — below the forecast
    TLS floor and tight enough that even the plain-HTTP Asgard push failed to
    allocate a socket (ESP_ERR_HTTP_CONNECT). ESPHome runs SPIRAM in
    CAPS_ALLOC mode, so plain malloc()/new always lands in internal RAM; push
    Bluedroid's standing footprint to PSRAM / trim it instead:
    - CONFIG_BT_BLE_DYNAMIC_ENV_MEMORY: host env allocated to PSRAM
    - CONFIG_BT_CTRL_BLE_MAX_ACT 6->4: fewer controller activity slots (~828 B each)
    - CONFIG_BT_ACL_CONNECTIONS 4->1: scan-only, no GATT connections
    Frees ~14 KB internal heap (to ~30 KB), unblocking the Asgard push.
    Co-Authore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
2026-06-19 feat(forecast): SNTP clock, true fetch cadence, full-day cache, manual fetch
    The firmware had no time source, so the ESP clock stayed on the 1970 epoch:
    preload timing (now_index) compared it against real forecast epochs and
    silently never applied offsets, and the dashboard showed a bogus "1 Jan"
    update time. Add SNTP and gate the producer on a synced clock.
    Forecast component:
    - time: platform sntp; skip fetch until the epoch is valid (MIN_VALID_EPOCH)
    - track last_fetch_epoch_ (persisted in NVS) and measure both the refetch
    cadence and the "fetched X ago" age from it, not the forecast-hour offset
    - anchor hours_[0] at the start of the day (drop the skip-to-now) and query
    Open-Meteo wi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
    [hv6_dashboard.cpp]
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2026-06-19 fix: persist preheat advance; make help badges visible
    Preheat advance (preheat_advance_c_[]): the per-zone learned head-start
    was pure RAM and reset to 0 on every reboot, so the system had to
    re-learn from scratch after each restart.
    - Add preheat_advance_c to ZoneConfig (ZONE_CONFIG_VERSION 2 → 3)
    - Load from NVS on setup() so learned values survive reboots
    - Write back via update_zone() whenever the advance changes (episode
    end or decay), guarded by a != check so the NVS debounce timer is
    only kicked when the value actually changes
    Help badges: the "?" chip used --text-faint (56 % opacity) and
    --control-border (30 % opacity) — nearly invisible against the bold
    uppercase card titl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
    [hv6_types.h]
2026-06-19 Add measurement and position model documentation for Rev 2.1
    This commit introduces a new markdown file detailing the current, BEMF, engagement, and position model for the Rev 2.1 hardware. The document outlines the purpose of separating force measurement from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
    [bom.csv, heatvalve-6-rev2.1.kicad_pcb, heatvalve-6-rev2.1.kicad_sch]
2026-06-25 Add diagnostic and settings components for improved UI and functionality
    - Implemented `asgard-bridge-status-card` to display the status of the Asgard bridge, including role, setpoint, peer status, and last error.
    - Created `balancing-status-card` to show balancing status across multiple zones with prior, learned, effective values, and error indicators.
    - Developed `forecast-preload-status-card` to present live forecast preload offsets for each zone, including active offsets and peak load timings.
    - Introduced `settings-minimum-flow-card` for configuring minimum zone flow settings, allowing users to enable/disable and set minimum valve opening percentages.
